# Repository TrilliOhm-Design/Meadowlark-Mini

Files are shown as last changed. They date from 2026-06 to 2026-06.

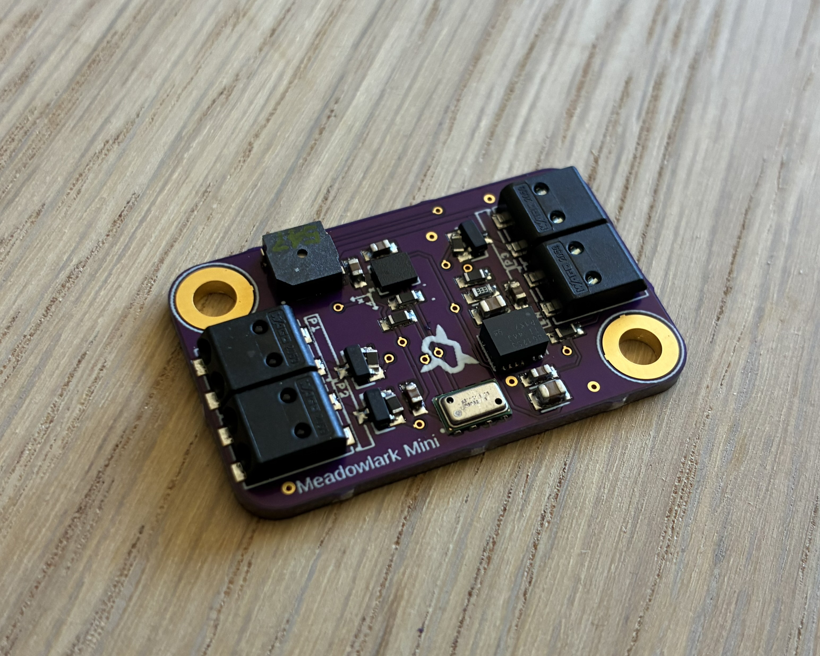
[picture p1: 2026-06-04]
Documentation/images/meadowlark-mini-v2_cover.jpg

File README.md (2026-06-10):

# Meadowlark-Mini

Dual deploy programable flight computer for amature rocketry. Equipped with a beeper, physical interrupt, battery monitoring, three pyro channels, IMU, and Pressure sensor. The goal is to offer a feature rich controller that can fit inside a 29mm chassis with the creature comforts of modern controllers. The system is powered by an ESP32-C6 microcontroller.  

Banner showing PCB

### Hardware Specs
* 10 to 1200 mbar operating range 
* +/- 2.5 mbar pressure error band
* +/- 0.012 mbar relative pressure accuracy
* +/- 32g accelerometer range
* +/- 2000 dps gyroscope
* embedded temperature compensation
* ~35mA operating consumption 
* Buzzer 80db
* 3 pyro channels
* Stable power supply (3-17V)

### Testing
- [x] Hardware validation
- [x] Firmware Initialized
- [ ] Test Functionallity
        - [x] Indicator light
        - [x] Pyro circuit
        - [x] Buzzer
        - [x] Pressure sensor
        - [x] IMU
        - [ ] Flight logs
        - [ ] HighPower supply
- [ ] Software endurance test
- [ ] Simulated flight test
- [ ] Passenger flight tests (collect data and tune triggers)
- [ ] Flight as main controller
- [ ] Flight as secondary controller

Repeat any tests until the controller passes with reliable behavior.

# Hardware
PCB size

The board is laid out such it has pyro channels on top and bottom. With two pyro channels on one side and an enable pin on the other. On the other side of the board you have a JST PH connector for power input from a 2s battery. 

I also wanted easy mounting so the board is mounted using two M3 screws.
### [Hardware Details](https://github.com/colinhalebrown/Meadowlark-Mini/tree/main/Hardware)

# Software

The board is equipped with WIFI, Bluetooth, LoRa and Zigbee. The ESP32-C6 has a built in antenna and a u.FL plug that the user can switch between. 

### Pinout
| System | Signal Type | Label | GPIO | Verified |
| --- | --- | --- | --- | --- |
| Indicator LED | Digital Output | D13 | GPIO13 | Y |
| Buzzer | Digital Output | A0 | GPIO26 | Y |
| Battery Monior  | Analog Input | A1 | AD1 | Y |
| Pyro 1 | Digital Output | D12 | GPIO12 | Y |
| Pyro 2 | Digital Output | D3 | GPIO6 | Y |
| Pyro 3 | Digital Output | D6 | | Y |
| Pressure Sensor | I2C | SDA, SCL | GPIO2, GPIO3 | Y |
| IMU | I2C | SDA, SCL | GPIO2, GPIO3 | Y |

# Status
Currently the board needs software so it can get tested in flight as a payload.

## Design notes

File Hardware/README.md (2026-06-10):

# Meadowlark-Mini Hardware

Banner showing PCB

### Known Issues
* none

Boards have paste added using a stencil

PCB with paste

Components are added to the board by hand 

Top of board pre bake

The board is then baked and the solder joints inspected. Board tested for shorts. After testing the board either needs rework or is cleared for a microcontroller. The controller and power plug are soldiered by hand to the bottom.

Bottom of Board

The boards are then tested and conformal coated once all rework as been completed. Ports, Plugs, buttons, and sensors are avoided to prevent loss of functionality. 

The enclosure was removed to save weight and allow for users to incorporate the board into their AV bays easier.

PCB on its side

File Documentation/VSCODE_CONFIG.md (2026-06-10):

## Prereqs
- Arduino IDE 2.3.9
- Arduino CLI 1.5.1

## VS Code Extensions
- `vscode-arduino.vscode-arduino-community`

## Boards
add this url to additional boards manager:
```
https://github.com/earlephilhower/arduino-pico/releases/download/global/package_rp2040_index.json
```

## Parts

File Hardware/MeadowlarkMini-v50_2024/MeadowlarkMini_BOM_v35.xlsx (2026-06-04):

Meadowlark Mini BOM
Comment | Designator | Footprint | Part # | URL | QTY | Type | Notes
MLT-5020 | U$9 | MLT5020 | C94598 | JLC (https://jlcpcb.com/partdetail/Jiangsu_HuanengElec-MLT5020/C94598) | 1 | Extended | Buzzer
S2B-PH-SM4-TB | P1 | JST_S2B-PH-SM4-TB(LF)(SN) | C295747 | JLC (https://jlcpcb.com/partdetail/Jst-S2B_PH_SM4_TB_LF_SN/C295747) | 1 | Extended | JST-PH 2P
RP2040 | RP2040 | QFN56_7MM_REDUCEDEPAD | C2040 | JLC (https://jlcpcb.com/partdetail/RaspberryPi-RP2040/C2040) | 1 | Extended | RP2040 SOC
TF-04A | J1 | TF04A | C145799 | JLC (https://jlcpcb.com/partdetail/Korean_HropartsElec-TF04A/C145799) | 1 | Extended | MicroSD Slot
DB125-2.54-4P-GN-S | J3 | VN04A1500000G | C918122 | JLC (https://jlcpcb.com/partdetail/Dorabo-DB125_2_54_4P_GNS/C918122) | 1 | Extended | 4P 2.54mm Screw
DB301V-3.5-2P-GN-S | J2 | VN02A1500000G | C918120 | JLC (https://jlcpcb.com/partdetail/Dorabo-DB125_2_54_2P_GNS/C918120) | 1 | Extended | 2P 2.54mm Screw
W25Q64JVXGIQ | U1 | USON8_4X4 | C2940195 | JLC (https://jlcpcb.com/partdetail/WinbondElec-W25Q64JVXGIQ/C2940195) | 1 | Extended | Flash Storage
ICM-42670-P | IC1 | ICM42670P | C3288646 | JLC (https://jlcpcb.com/partdetail/TdkInvensense-ICM_42670P/C3288646) | 1 | Extended | IMU
LPS22HHTR | IC2 | LPS22HHTR | C2827824 | JLC (https://jlcpcb.com/partdetail/Stmicroelectronics-LPS22HHTR/C2827824) | 1 | Extended | Barometer
SI2301CDS-T1-GE3 | Q3 | SOT23-R | C10487 | JLC (https://jlcpcb.com/partdetail/VishayIntertech-SI2301CDS_T1GE3/C10487) | 1 | Basic | Power MOSFET
RT9080-33GJ5 | U2 | SOT23-5 | C841192 | JLC (https://jlcpcb.com/partdetail/RichtekTech-RT908033GJ5/C841192) | 1 | Extended | Voltage regulator
MCP73831T-2ACI/OT | U3 | SOT23-5 | C424093 | JLC (https://jlcpcb.com/partdetail/MicrochipTech-MCP73831T_2ACIOT/C424093) | 1 | Extended | LIPO Charger
TYPE-C 16PIN 2MD(073) | X1 | USB_C_CUSB31-CFM2AX-01-X | C2765186 | JLC (https://jlcpcb.com/partdetail/ShouHan-TYPE_C_16PIN_2MD_073/C2765186) | 1 | Extended | USB-C port
AO3400A | Q1, Q2 | SOT23-WIDE | C20917 | JLC (https://jlcpcb.com/partdetail/Alpha_OmegaSemicon-AO3400A/C20917) | 2 | Basic | Load MOSFET
0402WGF1001TCE | R24, R26 | RESC1005X40 | C11702 | JLC (https://jlcpcb.com/partdetail/12256-0402WGF1001TCE/C11702) | 2 | Basic | 1k 0402
1N5819WS | D1, D4 | SOD-323_MINI | C191023 | JLC (https://jlcpcb.com/partdetail/GuangdongHottech-1N5819WS/C191023) | 2 | Basic | Original Part (https://jlcpcb.com/partdetail/Onsemi-NSR0320MW2T1G/C48192)
0402WGF1002TCE | R1, R2, R3, R6, R7, R11, R13, R14, R15, R16, R21 | RESC1005X40 | C25744 | JLC (https://jlcpcb.com/partdetail/26487-0402WGF1002TCE/C25744) | 13 | Basic | 10k 0402
CL05A106MQ5NUNC | C1, C4, C5, C18, C20, C21 | CAPC1005X60 | C15525 | JLC (https://jlcpcb.com/partdetail/16204-CL05A106MQ5NUNC/C15525) | 6 | Basic | 10uF 0402
CL05B104KB54PNC | C6, C7, C9, C11, C12, C13, C14, C15, C16, C17, C19 | CAPC1005X60 | C307331 | JLC (https://jlcpcb.com/partdetail/291005-CL05B104KB54PNC/C307331) | 11 | Basic | 0.1uF 0402
CL05B103KB5NNNC | C22 | CAPC1005X60 | C15195 | JLC (https://jlcpcb.com/partdetail/15869-CL05B103KB5NNNC/C15195) | 1 | Basic | 10nF 0402
KT-0603R | D2, D3, D6, D7 | LEDC1608X55N_FLAT-R | C2286 | JLC (https://jlcpcb.com/partdetail/Hubei_KentoElec-KT0603R/C2286) | 4 | Basic | Red LED 0603
19-213/Y2C-CQ2R2L/3T(CY) | D5 | LEDC1608X55N_FLAT-Y | C72038 | JLC (https://jlcpcb.com/partdetail/73147-19_213_Y2C_CQ2R2L_3T_CY/C72038) | 1 | Basic | Yellow LED 0603
0402WGF5101TCE | R8, R10, R12 | RESC1005X40 | C25905 | JLC (https://jlcpcb.com/partdetail/26648-0402WGF5101TCE/C25905) | 3 | Basic | 5.1k 0402
0402WGF4702TCE | R4, R17, R18, R20, R22, R23 | RESC1005X40 | C25792 | JLC (https://jlcpcb.com/partdetail/26535-0402WGF4702TCE/C25792) | 6 | Basic | 47k 0402
0402CG330J500NT | C2, C3 | CAPC1005X60 | C1562 | JLC (https://jlcpcb.com/partdetail/1914-0402CG330J500NT/C1562) | 2 | Basic | 33pF 0402
X322512MSB4SI | Y1 | X322512MSB4SI | C9002 | JLC (https://jlcpcb.com/partdetail/Yxc-X322512MSB4SI/C9002) | 1 | Basic | Clock Cystal
CL05A105KA5NQNC | C8, C10 | CAPC1005X60 | C52923 | JLC (https://jlcpcb.com/partdetail/53938-CL05A105KA5NQNC/C52923) | 2 | Basic | 1uF 0402
0402WGF270JTCE | R5, R9 | RESC1005X40 | C25100 | JLC (https://jlcpcb.com/partdetail/25843-0402WGF270JTCE/C25100) | 2 | Extended | 27 0402

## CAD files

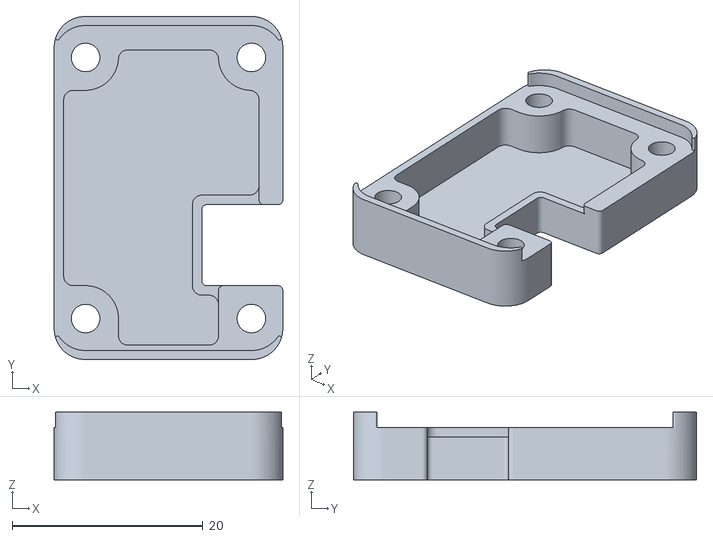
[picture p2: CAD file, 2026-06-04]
Hardware/MeadowlarkMini-v50_2024/Case_Bottom-v6.stl
24.0 x 36.0 x 7.10

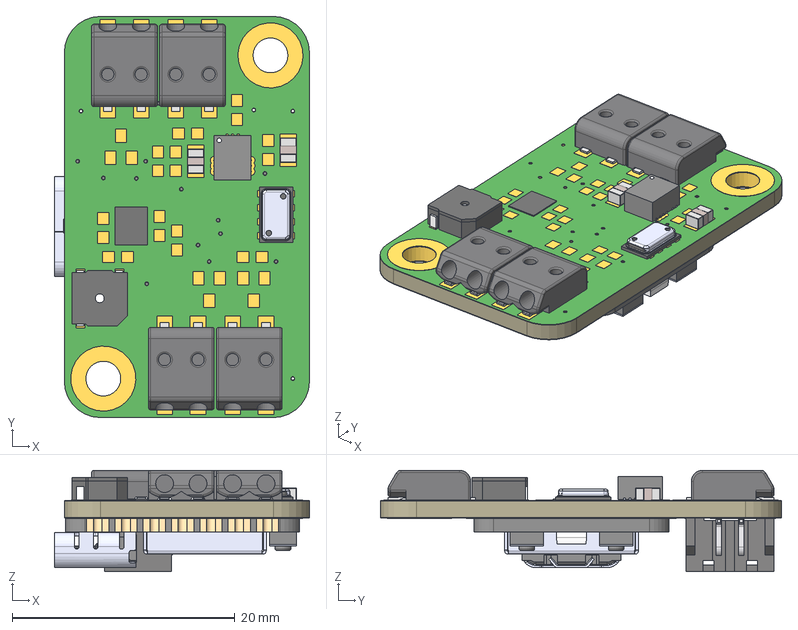
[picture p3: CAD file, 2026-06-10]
Hardware/MeadowlarkMini-v86/Meadowlark Mini Board.step
22.9 x 36.0 x 9.11 mm
Board
1-copper
16-copper
1-soldermask
16-soldermask
temp_import.SLDPRT
CAPC2012X110 x 2
LGA-14L
2059-322/998-403 x 4
XIAO-ESP32-C6-SMD
VREG_TPSM861253RDXR
零件2
零件1_1
MS561101BA03-50 v1

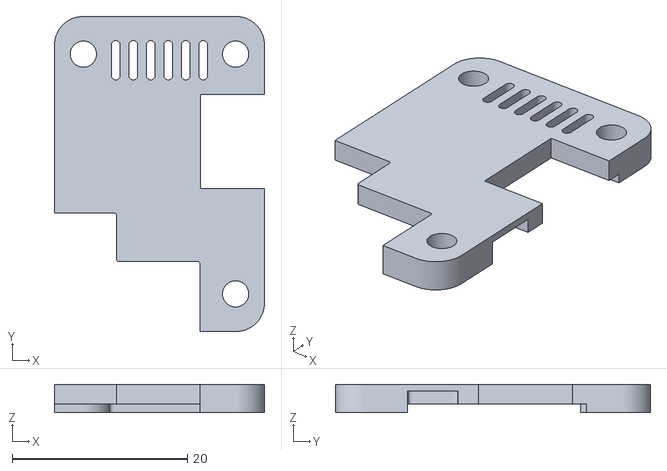
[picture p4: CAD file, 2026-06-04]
Hardware/MeadowlarkMini-v50_2024/Case_Top-v6.stl
24.0 x 36.0 x 3.25

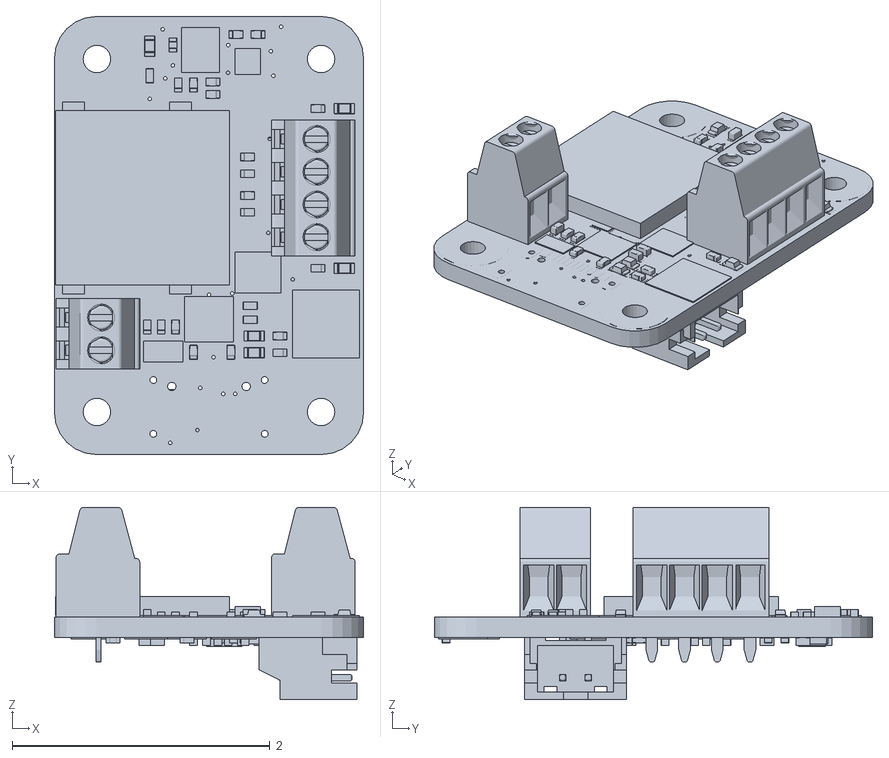
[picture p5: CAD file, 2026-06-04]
Hardware/MeadowlarkMini-v50_2024/Meadowlark Mini Board v17.obj
2.40 x 3.40 x 1.49

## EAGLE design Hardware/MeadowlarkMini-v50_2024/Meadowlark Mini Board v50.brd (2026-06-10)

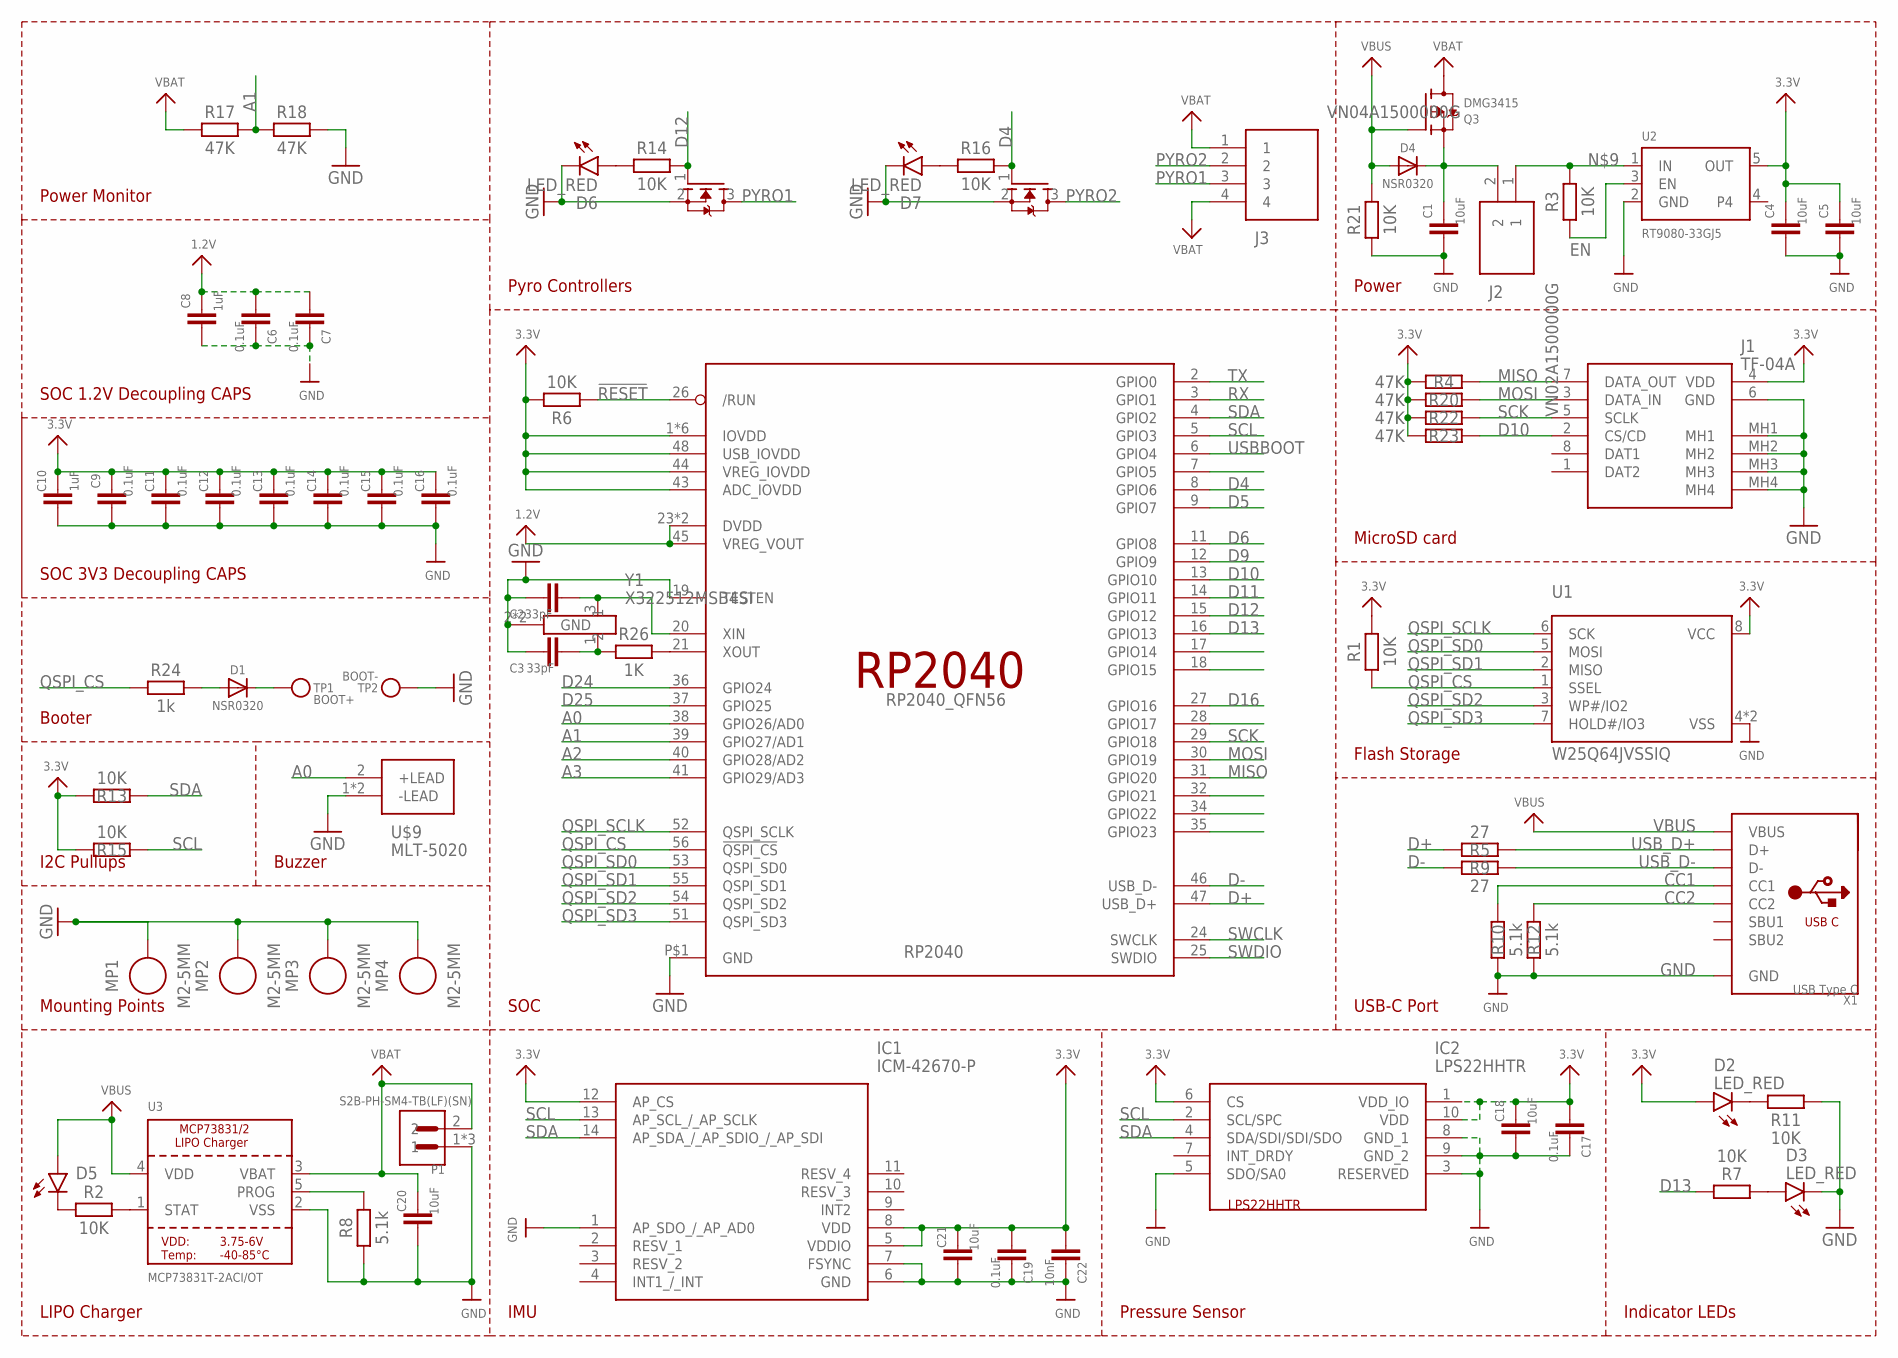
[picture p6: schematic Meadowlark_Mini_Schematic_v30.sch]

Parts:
C1, C4, C5, C18, C20, C21: 10uF; CAPC1005X60
C2, C3: 33pF; CAPC1005X60
C6, C7, C9, C11, C12, C13, C14, C15, C16, C17, C19: 0.1uF; CAPC1005X60
C8, C10: 1uF; CAPC1005X60
C22: 10nF; CAPC1005X60
D1, D4: NSR0320; SOD-323_MINI
D2, D3, D6, D7: LED_RED; LEDC1608X55N_FLAT-R
D5: LED_YELLOW; LEDC1608X55N_FLAT-Y
IC1: ICM-42670-P; ICM42670P
IC2: LPS22HHTR
J1: TF-04A; TF04A
J2: VN02A1500000G
J3: VN04A1500000G
MP1, MP2, MP3, MP4: M2-5MM; STANDOFF_HEX_MALE-FEMALE_400X500_M2X0.4_MTGP600H220
P1: S2B-PH-SM4-TB(LF)(SN); JST_S2B-PH-SM4-TB(LF)(SN)
Q1, Q2: AO3400A; SOT23-WIDE
Q3: DMG3415; SOT23-R
R1, R2, R3, R6, R7, R11, R13, R14, R15, R16, R21: 10K; RESC1005X40
R4, R17, R18, R20, R22, R23: 47K; RESC1005X40
R5, R9: 27; RESC1005X40
R8, R10, R12: 5.1k; RESC1005X40
R24: 1k; RESC1005X40
R26: 1K; RESC1005X40
RP2040: RP2040_QFN56; QFN56_7MM_REDUCEDEPAD
TP1: BOOT+; TESTPOINT_ROUND_1.5MM_NO
TP2: BOOT-; TESTPOINT_ROUND_1.5MM_NO
U1: W25Q64JVSSIQ; USON8_4X4
U2: RT9080-33GJ5; SOT23-5; JLC_ROTATION 0
U3: MCP73831T-2ACI/OT; SOT23-5
U$9: MLT-5020; MLT5020
X1: USB Type C; USB_C_CUSB31-CFM2AX-01-X
Y1: X322512MSB4SI

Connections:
1.2V: C6.2, C7.2, C8.1, RP2040.23 (DVDD), RP2040.45 (VREG_VOUT), RP2040.50 (DVDD)
3.3V: C4.1, C5.1, C9.1, C10.1, C11.1, C12.1, C13.1, C14.1, C15.1, C16.1, C17.2, C18.1, C19.2, C21.1, C22.2, D2.A, IC1.5 (VDDIO), IC1.8 (VDD), IC1.12 (AP_CS), IC2.1 (VDD_IO), IC2.6 (CS), IC2.10 (VDD), J1.4 (VDD), R1.2, R4.1, R6.2, R13.2, R15.2, R20.1, R22.1, R23.1, RP2040.1 (IOVDD), RP2040.10 (IOVDD), RP2040.22 (IOVDD), RP2040.33 (IOVDD), RP2040.42 (IOVDD), RP2040.43 (ADC_IOVDD), RP2040.44 (VREG_IOVDD), RP2040.48 (USB_IOVDD), RP2040.49 (IOVDD), U1.8 (VCC), U2.5 (OUT)
!RESET: R6.1, RP2040.26 (/RUN)
A0: RP2040.38 (GPIO26/AD0), U$9.2 (+LEAD)
A1: R17.2, R18.1, RP2040.39 (GPIO27/AD1)
A2: RP2040.40 (GPIO28/AD2)
A3: RP2040.41 (GPIO29/AD3)
CC1: R10.2, X1.A5 (CC1)
CC2: R12.2, X1.B5 (CC2)
D4: Q2.1 (G), R16.2, RP2040.8 (GPIO6)
D5: RP2040.9 (GPIO7)
D6: RP2040.11 (GPIO8)
D9: RP2040.12 (GPIO9)
D10: J1.2 (CS/CD), R23.2, RP2040.13 (GPIO10)
D11: RP2040.14 (GPIO11)
D12: Q1.1 (G), R14.2, RP2040.15 (GPIO12)
D13: R7.2, RP2040.16 (GPIO13)
D16: RP2040.27 (GPIO16)
D24: RP2040.36 (GPIO24)
D25: RP2040.37 (GPIO25)
D+: R5.1, RP2040.47 (USB_D+)
D-: R9.1, RP2040.46 (USB_D-)
EN: R3.1, U2.3 (EN)
GND: C1.2, C2.1, C3.1, C4.2, C5.2, C6.1, C7.1, C8.2, C9.2, C10.2, C11.2, C12.2, C13.2, C14.2, C15.2, C16.2, C17.1, C18.2, C19.1, C20.2, C21.2, C22.1, D3.C, D6.C, D7.C, IC1.1 (AP_SDO_/_AP_AD0), IC1.6 (GND), IC1.7 (FSYNC), IC2.3 (RESERVED), IC2.5 (SDO/SA0), IC2.8 (GND_1), IC2.9 (GND_2), J1.6 (GND), J1.MH1, J1.MH2, J1.MH3, J1.MH4, MP1.1, MP2.1, MP3.1, MP4.1, P1.1, P1.P1 (1), P1.P2 (1), Q1.2 (S), Q2.2 (S), R8.1, R10.1, R11.2, R12.1, R18.2, R21.1, RP2040.19 (TESTEN), RP2040.P$1 (GND), TP2.P$1, U1.4 (VSS), U1.PAD (VSS), U2.2 (GND), U3.2 (VSS), U$9.1 (-LEAD), U$9.3 (-LEAD), X1.A1B12 (GND), X1.B1A12 (GND), Y1.2 (GND), Y1.4 (GND)
MISO: J1.7 (DATA_OUT), R4.2, RP2040.31 (GPIO20)
MOSI: J1.3 (DATA_IN), R20.2, RP2040.30 (GPIO19)
unnamed: D5.C, R2.1
unnamed: D2.C, R11.1
unnamed: R2.2, U3.1 (STAT)
unnamed: R8.2, U3.5 (PROG)
unnamed: D6.A, R14.1
unnamed: C3.2, R26.1, Y1.1
unnamed: R26.2, RP2040.21 (XOUT)
unnamed: D1.A, R24.2
unnamed: J2.1, R3.2, U2.1 (IN)
unnamed: D3.A, R7.1
unnamed: D7.A, R16.1
unnamed: C2.2, RP2040.20 (XIN), Y1.3 (2)
PYRO1: J3.3, Q1.3 (D)
PYRO2: J3.2, Q2.3 (D)
QSPI_CS: R1.1, R24.1, RP2040.56 (!QSPI_CS), U1.1 (SSEL)
QSPI_SCLK: RP2040.52 (QSPI_SCLK), U1.6 (SCK)
QSPI_SD0: RP2040.53 (QSPI_SD0), U1.5 (MOSI)
QSPI_SD1: RP2040.55 (QSPI_SD1), U1.2 (MISO)
QSPI_SD2: RP2040.54 (QSPI_SD2), U1.3 (WP#/IO2)
QSPI_SD3: RP2040.51 (QSPI_SD3), U1.7 (HOLD#/IO3)
RX: RP2040.3 (GPIO1)
SCK: J1.5 (SCLK), R22.2, RP2040.29 (GPIO18)
SCL: IC1.13 (AP_SCL_/_AP_SCLK), IC2.2 (SCL/SPC), R15.1, RP2040.5 (GPIO3)
SDA: IC1.14 (AP_SDA_/_AP_SDIO_/_AP_SDI), IC2.4 (SDA/SDI/SDI/SDO), R13.1, RP2040.4 (GPIO2)
SWCLK: RP2040.24 (SWCLK)
SWDIO: RP2040.25 (SWDIO)
TX: RP2040.2 (GPIO0)
USBBOOT: D1.C, RP2040.6 (GPIO4), TP1.P$1
USB_D+: R5.2, X1.A6 (D+), X1.B6 (D+)
USB_D-: R9.2, X1.A7 (D-), X1.B7 (D-)
VBAT: C20.1, J3.1, J3.4, P1.2, Q3.3 (D), R17.1, U3.3 (VBAT)
VBUS: D4.A, D5.A, Q3.1 (G), R21.2, U3.4 (VDD), X1.A4B9 (VBUS), X1.B4A9 (VBUS)
VHI: C1.1, D4.C, J2.2, Q3.2 (S)

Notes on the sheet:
Power
LIPO Charger
MicroSD card
Flash Storage
USB-C Port
SOC
Pyro Controllers
IMU
Pressure Sensor
I2C Pullups
Indicator LEDs
Mounting Points
Buzzer
Booter
SOC 3V3 Decoupling CAPS
SOC 1.2V Decoupling CAPS
Power Monitor

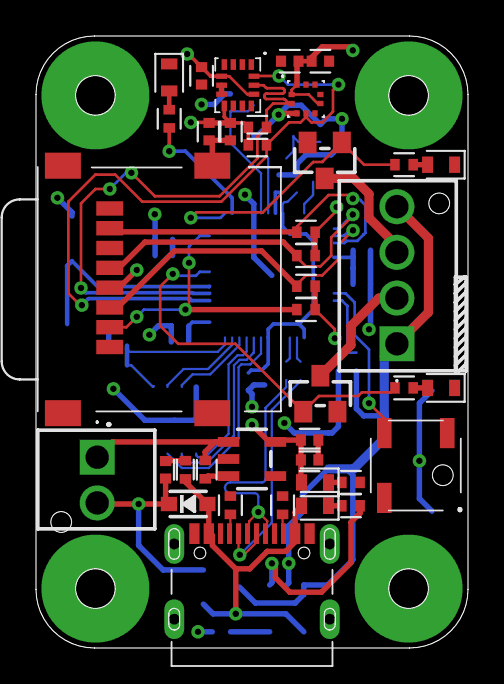
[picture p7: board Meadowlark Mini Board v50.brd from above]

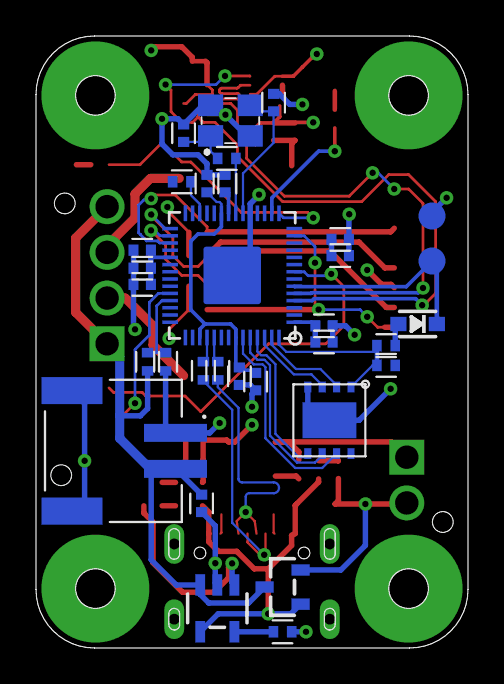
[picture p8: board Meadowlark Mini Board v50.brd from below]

Board: 2 copper layers, 24.0 x 34.0 mm, 75 parts (32 on the bottom side), 46 nets.

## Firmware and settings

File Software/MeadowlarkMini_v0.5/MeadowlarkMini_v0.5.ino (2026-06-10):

/* ----------------------------------------------------------------------------
 *  Meadowlark Mini Flight Computer
 *  Target  : Seeed Studio XIAO RP2040  (arduino-pico / Earle Philhower core)
 *  Sensors : LSM6DSO32  6-axis IMU (+/-32 g)   -  flight event triggering
 *            MS561101BA03-50 (MS5611) barometer -  altitude / apogee
 *  Outputs : Buzzer, 3 pyro channels, user LED
 *
 *  This firmware:
 *    1. Runs a 1-D Kalman filter (altitude / velocity / accel-bias) driven by
 *       the IMU for low-latency event timing. The barometer is decoupled
 *       during boost and high-speed flight (it lags and is Mach-corrupted) and
 *       only corrects the filter once slow - i.e. near apogee and on descent.
 *       See Estimator.ino.
 *    2. Normalises the IMU at power-up so the board may be mounted in ANY
 *       orientation - it learns the gravity vector on the pad and works in the
 *       rocket's "up" axis from then on.
 *    3. Runs the RP2040 hardware watchdog so a hang in flight forces a reboot.
 *    4. Plays a chime once the unit has calibrated, is armed, and is sitting in
 *       STANDBY ready for flight.
 *    5. Enters an interactive CONFIG mode over USB (send any key within 3 s of
 *       power-up) to calibrate sensors, edit & save flight variables to flash,
 *       and ground-test the buzzer / LED / pyro outputs before flight.
 *    6. Logs each flight: the last three flights' apogee / max-g / duration are
 *       kept in flash, and a full flight profile is recorded in RAM and can be
 *       downloaded as CSV over USB after recovery (see DataLog.ino).
 *
 *  Sketch tabs:
 *    Calibration.ino       - on-pad sensor / orientation calibration
 *    Estimator.ino         - IMU + Kalman filter (altitude / velocity)
 *    ConfigMode.ino        - USB console, settings persistence, ground tests
 *    FlightStateMachine.ino- flight state transitions & event triggering
 *    DataLog.ino           - flight summaries (flash) + RAM profile / CSV
 *
 *  Pinout:
 *    D4  = SDA
 *    D5  = SCL
 *    D3  = Pyro 1   (drogue / apogee)
 *    D6  = Pyro 2   (main  / altitude)
 *    D1  = Pyro 3   (apogee backup)
 *    A0  = Buzzer
 *    A2  = Battery mon
 *    D10 = User LED
 *
 * --------------------------------------------------------------------------*/

#include <Wire.h>
#include <EEPROM.h>
#include <Adafruit_LSM6DSO32.h>
#include "MS5611.h"

// ----------------------------------------------------------------------------
//  Pin assignments
// ----------------------------------------------------------------------------
#define PIN_SDA       D4
#define PIN_SCL       D5
#define PIN_PYRO_1     D3      // Drogue   - fires at apogee
#define PIN_PYRO_2     D6      // Main     - fires at MAIN_DEPLOY_ALT on descent
#define PIN_PYRO_3     D1      // Backup   - apogee redundancy
#define PIN_BUZZER    A0
#define PIN_VBAT      A2
#define PIN_USER_LED  D10     // external user LED (note: core's PIN_LED is the
                              // XIAO's onboard LED on GP17 - don't reuse it)

const uint8_t PYRO_PINS[3] = { PIN_PYRO_1, PIN_PYRO_2, PIN_PYRO_3 };

// ----------------------------------------------------------------------------
//  Flight configuration  -  TUNE THESE FOR YOUR VEHICLE
// ----------------------------------------------------------------------------
const float    G0                  = 9.80665f;  // standard gravity (m/s^2)

// --- Loop timing. 100 Hz for fast event reaction; the barometer is decoupled
//     during high-speed flight (see Estimator.ino) so it never bottlenecks the
//     loop when it matters. The estimator uses the measured dt, not this value.
const uint32_t LOOP_HZ             = 100;                // main control rate
const uint32_t LOOP_DT_US         = 1000000UL / LOOP_HZ;
const float    DT                  = 1.0f / LOOP_HZ;     // nominal step (s)

// --- Watchdog (RP2040 hardware WDT, max ~8.3 s)
const uint32_t WDT_TIMEOUT_MS     = 4000;

// --- Calibration (must be stationary & vertical on the pad)
const uint16_t CAL_SAMPLES         = 400;    // samples averaged for bias/gravity
const float    CAL_MOTION_TOL      = 1.5f;   // m/s^2 spread allowed during cal

// --- Detection tuning that is NOT user-editable (compile-time)
//     Sample counts are sized for the 100 Hz loop (~10 ms/sample).
const uint8_t  LAUNCH_CONFIRM      = 8;          // ~80 ms sustained over threshold
const uint8_t  BURNOUT_CONFIRM     = 12;         // ~120 ms
const uint32_t MIN_BOOST_MS        = 150;        // ms ignore burnout before this
const float    APOGEE_VEL_MS       = 0.0f;       // m/s descending when v < this
const uint8_t  APOGEE_CONFIRM      = 16;         // ~160 ms 

// --- Landing detection
const float    LANDED_VEL_MS       = 1.0f;       // |v| under this ...
const uint32_t LANDED_HOLD_MS      = 5000;       // ... for this long => landed

// --- Battery ADC scaling (the divider ratio itself is a user setting)
const float    ADC_VREF            = 3.30f;      // ADC reference (V)
const uint16_t ADC_MAX             = 4095;       // 12-bit

// --- IMU low-pass cut-offs (Hz). Light filtering only: the Kalman filter does
//     the heavy lifting, and we keep IMU latency low for fast event detection.
const float    LP_FC_ACCEL         = 30.0f;
const float    LP_FC_GYRO          = 30.0f;
// (Altitude/velocity are produced by the Kalman filter in Estimator.ino, which
//  fuses the IMU with the barometer - the latter only at low speed.)

// --- Barometer oversampling: balance precision vs. conversion time.
//     OSR_STANDARD (~4 ms/read) fits the 10 ms loop budget at 100 Hz.
const osr_t    BARO_OSR            = OSR_STANDARD;

// ----------------------------------------------------------------------------
//  User-tunable flight settings
//  These are editable over USB in CONFIG mode and persisted to flash (EEPROM
//  emulation) so they survive power cycles. Defaults are applied on first boot
//  or whenever the stored MAGIC/VERSION does not match.
// ----------------------------------------------------------------------------
struct Config {
  uint32_t magic;
  uint16_t version;
  float    mainDeployAltAGL;   // m AGL, main chute fires on descent below this
  float    launchAccelG;       // g, |a| above this => liftoff
  float    burnoutAccelG;      // g, |a| below this => motor burnout
  float    apogeeAltMargin;    // m below peak required to confirm apogee
  uint32_t apogeeBackupMs;     // delay after apogee before backup channel fires
  uint32_t pyroPulseMs;        // e-match firing pulse length
  bool     enableDrogue;       // Pyro 1 at apogee
  bool     enableMain;         // Pyro 2 at main-deploy altitude
  bool     enableBackup;       // Pyro 3 apogee backup
  float    vbatDivider;        // (R1+R2)/R2 of the battery divider
  float    vbatLow;            // low-battery warning threshold (V)
  float    baroGateVel;        // m/s; baro is ignored above this speed (Mach/lag)
};

#define CFG_MAGIC    0x4D4C4B31UL   // 'MLK1'
#define CFG_VERSION  2              // bumped when the Config layout changes

Config cfg;
// The struct and the live `cfg` instance are declared here (the main tab) so
// the flight code can read them. loadDefaults()/loadConfig()/saveConfig() live
// in ConfigMode.ino.

// ----------------------------------------------------------------------------
//  Sensors
// ----------------------------------------------------------------------------
Adafruit_LSM6DSO32 imu;
MS5611             baro(0x77, &Wire);   // 0x76 if CSB tied high

// ----------------------------------------------------------------------------
//  Flight state machine
// ----------------------------------------------------------------------------
enum FlightState {
  ST_BOOT,        // power-up, hardware init
  ST_CONFIG,      // USB connected: calibrate / set variables / ground test
  ST_CALIBRATE,   // learning bias / gravity vector / ground level
  ST_STANDBY,     // armed, on the pad, waiting for launch  (chime here)
  ST_BOOST,       // motor burning
  ST_COAST,       // burnout -> apogee
  ST_DROGUE,      // apogee passed, drogue out, descending
  ST_MAIN,        // main chute deployed
  ST_LANDED       // touchdown, report apogee
};
FlightState state = ST_STANDBY; // go into ST_BOOT For SPI NAND Conig in future

// ----------------------------------------------------------------------------
//  First-order low-pass (exponential) filter
// ----------------------------------------------------------------------------
struct LowPass {
  float y = 0.0f;
  float a = 1.0f;
  bool  init = false;
  void  setCutoff(float fc, float dt) {        // a = dt / (RC + dt)
    float rc = 1.0f / (2.0f * PI * fc);
    a = dt / (rc + dt);
  }
  float update(float x) {
    if (!init) { y = x; init = true; }
    y += a * (x - y);
    return y;
  }
  void reset() { init = false; y = 0.0f; }
};

LowPass lpAx, lpAy, lpAz;     // accelerometer (m/s^2)
LowPass lpGx, lpGy, lpGz;     // gyro (rad/s)

// ----------------------------------------------------------------------------
//  Estimator / orientation state
// ----------------------------------------------------------------------------
float  upHat[3]    = {0, 0, 1};   // unit gravity vector at rest = rocket "up"
float  gyroBias[3] = {0, 0, 0};   // rad/s, removed in flight
float  groundPressure = 1013.25f; // hPa baseline captured on the pad

float  altAGL      = 0.0f;        // Kalman altitude above ground (m)
float  velEst      = 0.0f;        // Kalman vertical velocity (m/s, up +)
float  maxAltAGL   = 0.0f;        // peak altitude this flight (m)
float  vbat        = 0.0f;

// detection counters / timestamps
uint8_t  launchCount = 0, burnoutCount = 0, apogeeCount = 0;
uint32_t tBoost = 0, tApogee = 0, tLandedStart = 0;
bool     apogeeBackupArmed = false;

// pyro channel non-blocking fire timers (0 = idle)
uint32_t pyroOffAt[3]  = {0, 0, 0};
bool     pyroFired[3]  = {false, false, false};

uint32_t lastLoopUs = 0;

// Estimator outputs shared with the state machine.
float  gAccMag  = 0.0f;   // total specific-force magnitude (m/s^2)
float  gNetVert = 0.0f;   // vertical acceleration, gravity removed (m/s^2)

// ----------------------------------------------------------------------------
//  Buzzer - non-blocking tune sequencer
// ----------------------------------------------------------------------------
struct Note { uint16_t freq; uint16_t dur; };   // freq 0 = silent rest

const Note* tunePtr = nullptr;
uint16_t    tuneLen = 0, tuneIdx = 0;
uint32_t    noteStartMs = 0;
bool        tunePlaying = false;

// READY / STANDBY chime: ascending C-E-G-C, "armed and happy"
const Note TUNE_READY[] = {
  {523, 120}, {659, 120}, {784, 120}, {1047, 260}
};
// Liftoff acknowledge (brief, won't block the control loop)
const Note TUNE_LAUNCH[] = { {1047, 80}, {1319, 80} };
// Apogee
const Note TUNE_APOGEE[] = { {1319, 120}, {988, 120} };
// Error / not armed: low repeated buzz
const Note TUNE_ERROR[]  = { {220, 200}, {0, 120}, {220, 200}, {0, 120}, {220, 400} };

void startCurrentNote(uint32_t now) {
  noteStartMs = now;
  uint16_t f = tunePtr[tuneIdx].freq;
  if (f > 0) tone(PIN_BUZZER, f);
  else       noTone(PIN_BUZZER);
}

void playTune(const Note* t, uint16_t len) {
  tunePtr = t; tuneLen = len; tuneIdx = 0;
  tunePlaying = (len > 0);
  if (tunePlaying) startCurrentNote(millis());
}

void updateBuzzer() {
  if (!tunePlaying) return;
  uint32_t now = millis();
  if (now - noteStartMs >= tunePtr[tuneIdx].dur) {
    tuneIdx++;
    if (tuneIdx >= tuneLen) { tunePlaying = false; noTone(PIN_BUZZER); return; }
    startCurrentNote(now);
  }
}

// Altitude "beep-out" for after landing: builds a tune of per-digit beeps,
// e.g. 342 m -> 3 beeps . 4 beeps . 2 beeps. Zero digit -> one long low beep.
Note beepOutBuf[40];
void buildAltitudeBeepOut(uint32_t meters) {
  uint16_t n = 0;
  char digits[6];
  int d = snprintf(digits, sizeof(digits), "%lu", (unsigned long)meters);
  for (int i = 0; i < d && n < 36; i++) {
    int val = digits[i] - '0';
    if (val == 0) {
      beepOutBuf[n++] = {330, 500};            // long low beep = zero
    } else {
      for (int b = 0; b < val && n < 38; b++) {
        beepOutBuf[n++] = {880, 120};
        beepOutBuf[n++] = {0,   120};
      }
    }
    beepOutBuf[n++] = {0, 600};                // gap between digits
  }
  playTune(beepOutBuf, n);
}

// ----------------------------------------------------------------------------
//  Helpers
// ----------------------------------------------------------------------------
void setPyro(uint8_t ch, bool on) {
  digitalWrite(PYRO_PINS[ch], on ? HIGH : LOW);
}

// Fire a pyro channel as a timed pulse (non-blocking).
void firePyro(uint8_t ch) {
  if (pyroFired[ch]) return;          // one-shot per flight
  pyroFired[ch] = true;
  setPyro(ch, true);
  pyroOffAt[ch] = millis() + cfg.pyroPulseMs;
  Serial.print(F("[PYRO] channel ")); Serial.print(ch + 1); Serial.println(F(" FIRED"));
}

void servicePyro() {                  // turn channels back off after the pulse
  uint32_t now = millis();
  for (uint8_t i = 0; i < 3; i++) {
    if (pyroOffAt[i] && now >= pyroOffAt[i]) {
      setPyro(i, false);
      pyroOffAt[i] = 0;
    }
  }
}

float readBattery() {
  uint16_t raw = analogRead(PIN_VBAT);
  return (raw * ADC_VREF / ADC_MAX) * cfg.vbatDivider;
}

float pressureToAltitude(float p_hPa, float p0_hPa) {
  // International barometric formula (troposphere), result in metres AGL.
  return 44330.0f * (1.0f - powf(p_hPa / p0_hPa, 0.1902949f));
}

void feedWatchdog() { rp2040.wdt_reset(); }

// ----------------------------------------------------------------------------
//  setup()
// ----------------------------------------------------------------------------
void setup() {
  pinMode(PIN_PYRO_1, OUTPUT); digitalWrite(PIN_PYRO_1, LOW);
  pinMode(PIN_PYRO_2, OUTPUT); digitalWrite(PIN_PYRO_2, LOW);
  pinMode(PIN_PYRO_3, OUTPUT); digitalWrite(PIN_PYRO_3, LOW);
  pinMode(PIN_USER_LED, OUTPUT); digitalWrite(PIN_USER_LED, LOW);
  pinMode(PIN_BUZZER, OUTPUT);

  analogReadResolution(12);

  Serial.begin(115200);
  uint32_t t0 = millis();
  while (!Serial && (millis() - t0 < 1500)) { /* brief wait for USB */ }
  Serial.println(F("\n=== Meadowlark Mini Flight Computer ==="));

  // --- Load saved flight settings + flight summaries from flash
  EEPROM.begin(512);
  loadConfig();
  loadFlightLog();

  // --- I2C bus (default Wire maps to D4/D5 on the XIAO RP2040)
  Wire.setSDA(PIN_SDA);
  Wire.setSCL(PIN_SCL);
  Wire.begin();
  Wire.setClock(400000);

  bool ok = true;

  // --- IMU. The LSM6DSO32 lives at 0x6A or 0x6B depending on the SA0/SDO pin.
  //     This board straps it to 0x6B (the SparkFun-style default), so try the
  //     default 0x6A first, then 0x6B, rather than assuming one address.
  bool imuOk = imu.begin_I2C(0x6B, &Wire);   // 0x6A

  if (!imuOk) {
    Serial.println(F("[ERR] LSM6DSO32 not found at 0x6B!"));
    ok = false;
  } else {
    imu.setAccelRange(LSM6DSO32_ACCEL_RANGE_32_G);     // high-g for boost
    imu.setGyroRange(LSM6DS_GYRO_RANGE_2000_DPS);
    imu.setAccelDataRate(LSM6DS_RATE_208_HZ);
    imu.setGyroDataRate(LSM6DS_RATE_208_HZ);
  }

  // --- Barometer
  if (!baro.begin()) {
    Serial.println(F("[ERR] MS5611 not found!"));
    ok = false;
  } else {
    baro.setOversampling(BARO_OSR);
  }

  // --- Configure IMU low-pass filters (the Kalman filter handles alt/vel)
  lpAx.setCutoff(LP_FC_ACCEL, DT); lpAy.setCutoff(LP_FC_ACCEL, DT); lpAz.setCutoff(LP_FC_ACCEL, DT);
  lpGx.setCutoff(LP_FC_GYRO, DT);  lpGy.setCutoff(LP_FC_GYRO, DT);  lpGz.setCutoff(LP_FC_GYRO, DT);

  // --- Start the hardware watchdog (after slow init, before the flight loop)
  rp2040.wdt_begin(WDT_TIMEOUT_MS);

  if (!ok) {
    Serial.println(F("[ERR] Sensor init failed - NOT arming."));
    Serial.println(F("[ERR] Send any key to enter CONFIG mode for diagnostics."));
    playTune(TUNE_ERROR, sizeof(TUNE_ERROR) / sizeof(Note));
    // Flash/buzz the fault, but stay responsive: a keystroke drops into CONFIG
    // (e.g. to run 'i2cscan' / 'status') instead of locking the user out.
    while (!Serial.available()) {
      digitalWrite(PIN_USER_LED, (millis() / 200) & 1);
      updateBuzzer();
      if (!tunePlaying) playTune(TUNE_ERROR, sizeof(TUNE_ERROR) / sizeof(Note));
      feedWatchdog();
      delay(10);
    }
    while (Serial.available()) Serial.read();   // flush
    noTone(PIN_BUZZER);
    enterState(ST_CONFIG);
    return;                                     // fall through to loop() in CONFIG
  }

  vbat = readBattery();
  Serial.print(F("[BATT] ")); Serial.print(vbat, 2); Serial.println(F(" V"));

  // --- CONFIG vs FLIGHT decision: offer a short window to enter CONFIG mode.
  //     If a USB host is connected and the user sends any character, drop into
  //     the interactive setup. On battery (no host), nothing arrives and the
  //     unit proceeds straight to on-pad calibration and arming.
  Serial.println(F("\n>>> Send any key within 5 s to enter CONFIG mode"));
  Serial.println(F("    (or send a key any time while in STANDBY on the pad)."));
  bool wantConfig = false;
  uint32_t tWin = millis();
  while (millis() - tWin < 5000) {
    if (Serial.available()) {
      while (Serial.available()) Serial.read();   // flush
      wantConfig = true;
      break;
    }
    digitalWrite(PIN_USER_LED, (millis() / 100) & 1);  // fast blink = waiting
    feedWatchdog();
    delay(10);
  }
  digitalWrite(PIN_USER_LED, LOW);

  if (wantConfig) enterState(ST_CONFIG);
  else            state = ST_CALIBRATE;
}

// ----------------------------------------------------------------------------
//  Telemetry (Serial)
// ----------------------------------------------------------------------------
void telemetry() {
  // Stay quiet after landing so a CSV download is not interleaved with noise.
  if (state == ST_LANDED) return;
  static uint32_t last = 0;
  if (millis() - last < 100) return;   // 10 Hz
  last = millis();
  Serial.print(F("S:"));   Serial.print(state);
  Serial.print(F(" alt:")); Serial.print(altAGL, 1);
  Serial.print(F(" v:"));   Serial.print(velEst, 1);
  Serial.print(F(" max:")); Serial.print(maxAltAGL, 1);
  Serial.print(F(" |a|:")); Serial.print(gAccMag, 1);
  Serial.print(F(" vb:"));  Serial.print(vbat, 2);
  Serial.println();
}

// ----------------------------------------------------------------------------
//  loop()  -  fixed-rate scheduler
// ----------------------------------------------------------------------------
void loop() {
  uint32_t nowUs = micros();
  if ((uint32_t)(nowUs - lastLoopUs) < LOOP_DT_US) {
    updateBuzzer();        // keep the tune player smooth between ticks
    return;
  }
  lastLoopUs = nowUs;

  feedWatchdog();          // pet the dog every control tick

  // --- CONFIG mode: serve the USB console; no flight logic runs here.
  //     The console + ground-test implementation lives in ConfigMode.ino.
  if (state == ST_CONFIG) {
    serviceConfigMode();   // parse serial commands, run sensor stream
    servicePyro();         // ends any ground-test pyro pulse
    updateBuzzer();
    digitalWrite(PIN_USER_LED, (millis() / 500) & 1);  // slow blink = config
    return;
  }

  // --- Allow entering CONFIG from the pad at any time: if a USB host sends a
  //     byte while we are armed in STANDBY, drop into the console. This is the
  //     reliable way in if the 5 s boot window was missed.
  if (state == ST_STANDBY && Serial.available()) {
    while (Serial.available()) Serial.read();   // flush
    enterState(ST_CONFIG);
    return;
  }

  // --- Run calibration / arming sequence here so it shares the WDT-fed loop.
  if (state == ST_CALIBRATE) {
    if (calibrate()) {
      altAGL = 0; velEst = 0; maxAltAGL = 0;
      estimatorReset();          // zero the Kalman filter on the pad
      enterState(ST_STANDBY);
    } else {
      playTune(TUNE_ERROR, sizeof(TUNE_ERROR) / sizeof(Note));
      delay(800);          // brief pause, then retry (WDT fed above)
    }
    return;
  }

  updateEstimator();
  runStateMachine();
  dataLogTick();           // capture the flight profile into RAM
  servicePyro();
  updateBuzzer();
  telemetry();

  // After touchdown, serve the USB console so the flight can be downloaded as
  // CSV (the RAM profile is intact until power-off; summaries are in flash).
  if (state == ST_LANDED) serviceConfigMode();

  // Battery sampled slowly; warn (don't disarm) on low voltage in STANDBY.
  static uint32_t vbatNext = 0;
  if (millis() >= vbatNext) {
    vbatNext = millis() + 2000;
    vbat = readBattery();
    if (state == ST_STANDBY && vbat < cfg.vbatLow) {
      Serial.print(F("[WARN] Low battery: ")); Serial.print(vbat, 2); Serial.println(F(" V"));
    }
  }
}

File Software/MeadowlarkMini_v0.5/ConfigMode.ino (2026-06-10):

/* ----------------------------------------------------------------------------
 *  ConfigMode
 *
 *  Contents:
 *    - Flight-settings persistence to flash (EEPROM emulation)
 *    - The interactive USB console entered as ST_CONFIG before flight
 *    - Ground-test routines for the buzzer, LED and pyro outputs
 *
 *  Entered when a host is connected at boot (see the prompt in setup()). The
 *  main loop drives this file through serviceConfigMode() while in ST_CONFIG.
 * --------------------------------------------------------------------------*/

// ----------------------------------------------------------------------------
//  Settings persistence (flash via EEPROM emulation)
// ----------------------------------------------------------------------------
void loadDefaults() {
  cfg.magic            = CFG_MAGIC;
  cfg.version          = CFG_VERSION;
  cfg.mainDeployAltAGL = 150.0f;
  cfg.launchAccelG     = 2.5f;
  cfg.burnoutAccelG    = 1.2f;
  cfg.apogeeAltMargin  = 2.0f;
  cfg.apogeeBackupMs   = 1000;
  cfg.pyroPulseMs      = 1000;
  cfg.enableDrogue     = true;
  cfg.enableMain       = true;
  cfg.enableBackup     = true;
  cfg.vbatDivider      = 2.0f;
  cfg.vbatLow          = 3.50f;
  cfg.baroGateVel      = 100.0f;   // ignore baro above ~Mach 0.3 (lag/inaccuracy)
}

void saveConfig() {
  cfg.magic = CFG_MAGIC; cfg.version = CFG_VERSION;
  EEPROM.put(0, cfg);
  EEPROM.commit();
}

void loadConfig() {
  EEPROM.get(0, cfg);
  if (cfg.magic != CFG_MAGIC || cfg.version != CFG_VERSION) {
    loadDefaults();
    saveConfig();
  }
}

// ----------------------------------------------------------------------------
//  USB console state (private to this tab)
// ----------------------------------------------------------------------------
static char     cmdBuf[48];
static uint8_t  cmdLen        = 0;
static uint32_t lastCharMs    = 0;
static bool     streamSensors = false;

// Assemble a command line without blocking the loop. Tolerant of any serial-
// monitor setting: a command is dispatched on CR, LF or CRLF, OR - if the
// monitor sends no line ending at all - once input has been idle briefly.
static bool readSerialLine() {
  while (Serial.available()) {
    char c = Serial.read();
    lastCharMs = millis();
    if (c == '\n' || c == '\r') {           // end of line (any convention)
      if (cmdLen == 0) continue;            // swallow empty lines / CRLF's LF
      cmdBuf[cmdLen] = 0; cmdLen = 0;
      return true;
    }
    if (cmdLen < sizeof(cmdBuf) - 1) cmdBuf[cmdLen++] = c;
  }
  // Fallback for "No line ending": dispatch a buffered line once input settles.
  if (cmdLen > 0 && (millis() - lastCharMs) > 200) {
    cmdBuf[cmdLen] = 0; cmdLen = 0;
    return true;
  }
  return false;
}

void printConfigMenu() {
  Serial.println(F("\n===== MEADOWLARK CONFIG MODE ====="));
  Serial.println(F("help                  this menu"));
  Serial.println(F("get                   show all settings"));
  Serial.println(F("set <key> <value>     change a setting (keys below)"));
  Serial.println(F("    mainalt launchg burnoutg margin backupms pulsems"));
  Serial.println(F("    en_drogue en_main en_backup vbatdiv vbatlow barogate"));
  Serial.println(F("save                  write settings to flash"));
  Serial.println(F("defaults              restore default settings"));
  Serial.println(F("cal                   calibrate sensors (hold still & vertical)"));
  Serial.println(F("status                sensor + battery self-test"));
  Serial.println(F("i2cscan               list devices on the I2C bus"));
  Serial.println(F("stream                toggle live sensor stream"));
  Serial.println(F("test buzzer|led       exercise an output"));
  Serial.println(F("fire <n> CONFIRM      pulse pyro n (1-3) -- DISCONNECT E-MATCHES"));
  Serial.println(F("flights               show last 3 flights (apogee/maxG/duration)"));
  Serial.println(F("download              dump the RAM flight profile as CSV"));
  Serial.println(F("eraselog              clear stored flight summaries"));
  Serial.println(F("arm                   save & begin flight (calibrate -> standby)"));
  Serial.println(F("==================================\n"));
}
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

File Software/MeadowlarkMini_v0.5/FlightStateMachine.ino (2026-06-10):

/* ----------------------------------------------------------------------------
 *  FlightStateMachine
 *
 *  Owns the flight state transitions and the recovery-event triggering, plus
 *  the per-state entry actions (chimes, LED, and starting/ending the data log).
 *
 *  Flow:  STANDBY -> BOOST -> COAST -> DROGUE -> MAIN -> LANDED
 * --------------------------------------------------------------------------*/

// ----------------------------------------------------------------------------
//  State entry actions (chimes / LED / data-log hooks)
// ----------------------------------------------------------------------------
void enterState(FlightState s) {
  state = s;
  switch (s) {
    case ST_CONFIG:
      Serial.println(F("[STATE] CONFIG"));
      digitalWrite(PIN_USER_LED, HIGH);
      printConfigMenu();
      printSettings();
      break;
    case ST_STANDBY:
      Serial.println(F("[STATE] STANDBY - armed and ready for flight"));
      digitalWrite(PIN_USER_LED, HIGH);
      dataLogReset();                                            // arm the logger
      playTune(TUNE_READY, sizeof(TUNE_READY) / sizeof(Note));   // ready chime
      break;
    case ST_BOOST:
      Serial.println(F("[STATE] BOOST"));
      dataLogBegin();                                            // start recording
      playTune(TUNE_LAUNCH, sizeof(TUNE_LAUNCH) / sizeof(Note));
      break;
    case ST_COAST:   Serial.println(F("[STATE] COAST")); break;
    case ST_DROGUE:
      Serial.println(F("[STATE] APOGEE -> DROGUE"));
      playTune(TUNE_APOGEE, sizeof(TUNE_APOGEE) / sizeof(Note));
      break;
    case ST_MAIN:    Serial.println(F("[STATE] MAIN")); break;
    case ST_LANDED:
      Serial.println(F("[STATE] LANDED"));
      dataLogEnd();                          // freeze RAM log, save flash summary
      break;
    default: break;
  }
}

// ----------------------------------------------------------------------------
//  Per-tick flight logic
// ----------------------------------------------------------------------------
void runStateMachine() {
  uint32_t now = millis();
  switch (state) {

    case ST_STANDBY:
      // Detect liftoff by total specific force (orientation independent).
      if (gAccMag > cfg.launchAccelG * G0) {
        if (++launchCount >= LAUNCH_CONFIRM) {
          tBoost = now;
          enterState(ST_BOOST);
        }
      } else launchCount = 0;
      break;

    case ST_BOOST:
      // Burnout when thrust falls away (|a| drops toward free-fall/drag).
      if (now - tBoost > MIN_BOOST_MS && gAccMag < cfg.burnoutAccelG * G0) {
        if (++burnoutCount >= BURNOUT_CONFIRM) enterState(ST_COAST);
      } else burnoutCount = 0;
      break;

    case ST_COAST:
      // Apogee: barometric velocity has gone negative AND we have dropped a
      // small margin below the peak. Baro is primary here; it is immune to the
      // accelerometer's free-fall ambiguity.
      if (velEst < APOGEE_VEL_MS && altAGL < (maxAltAGL - cfg.apogeeAltMargin)) { // add or aggressive check on each sensor to prevent single failure mode 
        if (++apogeeCount >= APOGEE_CONFIRM) {
          tApogee = now;
          apogeeBackupArmed = true;
          if (cfg.enableDrogue) firePyro(0);   // Pyro 1 = drogue
          enterState(ST_DROGUE);
        }
      } else apogeeCount = 0;
      break;

    case ST_DROGUE:
      // Redundant apogee event on Pyro 3 a moment later.
      if (apogeeBackupArmed && now - tApogee >= cfg.apogeeBackupMs) {
        if (cfg.enableBackup) firePyro(2);     // Pyro 3 = apogee backup
        apogeeBackupArmed = false;
      }
      // Main chute at the configured altitude on the way down.
      if (altAGL <= cfg.mainDeployAltAGL) {
        if (cfg.enableMain) firePyro(1);       // Pyro 2 = main
        enterState(ST_MAIN);
      }
      break;

    case ST_MAIN:
      // Touchdown when vertical velocity stays near zero for a while.
      if (fabsf(velEst) < LANDED_VEL_MS) {
        if (tLandedStart == 0) tLandedStart = now;
        else if (now - tLandedStart >= LANDED_HOLD_MS) enterState(ST_LANDED);
      } else tLandedStart = 0;
      break;

    case ST_LANDED:
      // Periodically beep out the recorded apogee (metres AGL).
      if (!tunePlaying) {
        static uint32_t lastBeepOut = 0;
        if (now - lastBeepOut > 4000) {
          lastBeepOut = now;
          buildAltitudeBeepOut((uint32_t)(maxAltAGL + 0.5f));
        }
      }
      break;

    default: break;
  }
}

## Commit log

2026-04-03 Code and board updates
2026-06-04 Reorganize Hardware Files
    [Case_Bottom-v6.stl, Case_Top-v6.stl, Meadowlark Mini Board v17.obj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]
2026-06-04 Add updated hardware
    [Meadowlark Mini Board.step]
2026-06-10 create inital dev container
    [Meadowlark Mini Board v50.brd, Meadowlark Mini Board.step, Meadowlark_Mini_Schematic_v30.sch]

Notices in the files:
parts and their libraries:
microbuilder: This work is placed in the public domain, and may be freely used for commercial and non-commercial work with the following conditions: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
